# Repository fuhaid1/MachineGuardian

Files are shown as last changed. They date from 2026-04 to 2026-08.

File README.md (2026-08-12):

# Machine Guardian

> Non-intrusive machine access control and energy monitoring for workshops and labs.
> Built entirely on an ESP32 — no cloud required.

System Overview

## What it does

Machine Guardian clamps onto the power line of any machine and watches for current draw. Employees authenticate with an NFC card before starting the machine. If the machine is started without a valid card, the system triggers an alarm, flashes the red LED, sounds the buzzer, and sends a Telegram alert — all without cutting power or touching the machine's wiring.

A built-in web dashboard (served directly from the ESP32) shows live current draw, session history, employee usage, and unauthorized access events. All data can be downloaded as a multi-sheet Excel file.

---

## Feature overview

| Feature | Detail |
|---|---|
| **Non-intrusive sensing** | SCT-013 current clamp — no wiring modifications |
| **NFC authentication** | PN532 module, MIFARE ISO14443A cards/fobs |
| **Ambient cancellation** | Subtracts room noise baseline so low-power machines are detectable |
| **Live web dashboard** | Served from ESP32 PROGMEM, no SD card or external server |
| **Real-time chart** | Current draw chart updates every 2 seconds with ambient/threshold lines |
| **Demo data** | Chart pre-fills with 3 days of historical demo data on first boot |
| **Employee management** | Add/remove/deactivate employees via the website, stored in NVS flash |
| **Unauthorized tracking** | Tracks runtime and power usage of unauth machine starts separately |
| **Telegram alerts** | HTTPS POST directly from ESP32 on unauthorized access |
| **Excel export** | Download full dataset (power log, runtime, operator summary, event log) |
| **Persistent config** | Ambient baseline, threshold, and employees survive reboots via NVS |
| **Threshold control** | Set detection threshold from the Settings page, no reflashing needed |

---

## Hardware required

| Component | Notes |
|---|---|
| ESP32 DevKit (38-pin) | Any ESP32 with ADC on pin 34 |
| SCT-013 current clamp (100A/50mA) | Bare CT output — **not** the -030 voltage variant |
| PN532 NFC/RFID module V3 | Set DIP switches to I2C mode: 1=ON, 2=OFF |
| SSD1306 OLED 0.91" I2C | Address 0x3C |
| Red, Green, Yellow LEDs | 5mm, any colour |
| Active buzzer | 3.3V compatible |
| Resistors | 3× 220Ω (LEDs), 2× 10kΩ (bias divider), 1× 33Ω 1% metal film (burden) |
| Capacitors *(optional)* | 10µF electrolytic (bias filter), 100nF ceramic × 3 (decoupling) — recommended for PCB builds |

**NFC cards/fobs:** any MIFARE Classic or MIFARE Ultralight card works. The system reads the UID only.

---

## Wiring

### Pin assignments

| Signal | ESP32 Pin |
|---|---|
| SCT-013 ADC input | 34 |
| I2C SDA (PN532 + OLED) | 21 |
| I2C SCL (PN532 + OLED) | 22 |
| Green LED | 18 |
| Red LED | 19 |
| Yellow LED | 5 |
| Buzzer | 23 |

### SCT-013 bias and burden circuit

The SCT-013 100A/50mA is a bare current-transformer (CT) that outputs current proportional to the line current. It needs two external circuits:

**Burden resistor** — converts CT current output to a voltage the ADC can read.
- Solder a **33Ω 1% metal film** resistor directly across OUT+ and OUT-.
- At 100A primary, the CT outputs 50mA × 33Ω = **1.65V peak** — within the 3.3V ADC range.

**Bias voltage divider** — shifts the AC signal up so it stays positive (ADC only reads 0–3.3V).
- 3.3V → 10kΩ → **node** → 10kΩ → GND
- Connect the **node** to OUT+ and to ESP32 pin 34.
- Add a **10µF** capacitor between the node and GND to stabilise the DC midpoint.

```
3.3V ─── 10kΩ ─── NODE ─── 10kΩ ─── GND
                    │  │
                   34  33Ω (burden across CT terminals)
                        │
                       GND
```

### PN532 I2C mode

Set the two DIP switches on the PN532 module: **switch 1 = ON, switch 2 = OFF**.  
The module shares the I2C bus with the OLED (SDA → pin 21, SCL → pin 22).

### LED wiring

Each LED: `ESP32 pin → 220Ω resistor → LED anode → LED cathode → GND`

### Buzzer

Active buzzer: `+` to pin 23, `–` to GND. If your buzzer draws more than 40mA, add an NPN transistor driver (2N2222): base via 1kΩ from pin 23, collector to buzzer+/3.3V, emitter to GND.

---

## PCB soldering guide

When soldering the final board, the layout choices below eliminate the PN532 interference that plagues breadboard builds.

### Component placement zones

```
┌─────────────────────────────────────────────────┐
│  [CT Circuit]          │          [OLED]        │
│  Top-left corner       │       Top-right        │
│  Burden + bias divider │                        │
│  ADC trace ≤3cm        │                        │
│                        │                        │
│         [ESP32 — centre of board]               │
│                                                 │
│  [LEDs + Buzzer]       │       [PN532]          │
│  Bottom-left           │   Bottom-right corner  │
│                        │   As far from CT as    │
│                        │   possible             │
└─────────────────────────────────────────────────┘
```

### Critical rules

1. **Ground plane** — pour copper fill on the bottom layer. Connect every GND pad to the plane via vias. This single change eliminates the majority of ADC noise.

2. **Star ground** — all GND traces meet at one point (the ESP32 GND pin), not daisy-chained.

3. **Decoupling capacitors** *(optional but recommended)* — place within 2mm of each VCC pin if you have them:
   - PN532: 100nF ceramic + 10µF electrolytic
   - OLED: 100nF ceramic
   - ESP32 3.3V pin: 100nF ceramic
   
   The firmware's `Wire.end()` trick handles most interference without caps. They improve ADC stability on a soldered PCB but are not required for the system to work.

4. **I2C pull-ups** — 4.7kΩ from SDA to 3.3V, 4.7kΩ from SCL to 3.3V. Check if your PN532 module already has them before adding more.

5. **ADC trace isolation** — route the ADC trace (node → pin 34) away from I2C traces. If they must cross, do so at 90°.

6. **CT cable** — twisted pair, ≤15cm. If using shielded cable, connect the shield to GND at the PCB end only (not both ends — that creates a ground loop).

---

## Software setup

### Prerequisites

- [PlatformIO](https://platformio.org/) (VS Code extension or CLI)
- ESP32 Arduino core (installed automatically by PlatformIO)

### Installation

```bash
git clone https://github.com/YOUR_USERNAME/machine-guardian.git
cd machine-guardian
```

Open `src/main.cpp` and fill in your credentials (the only lines you need to edit):

```cpp
// Wi-Fi
const char* WIFI_SSID     = "YOUR_WIFI_SSID";
const char* WIFI_PASSWORD = "YOUR_WIFI_PASSWORD";

// Telegram — leave both blank ("") to disable alerts
const char* TELEGRAM_TOKEN   = "";   // from @BotFather
const char* TELEGRAM_CHAT_ID = "";   // your personal or group chat ID
```

Then flash:

```bash
pio run --target upload
pio device monitor   # watch boot log and see your device's IP
```

---

## Telegram bot setup

1. Open Telegram and message **@BotFather** → `/newbot` → follow prompts → copy the **token**.
2. Send any message to your new bot (this starts the chat).
3. Open this URL in a browser (replace `<TOKEN>` with yours):
   ```
   https://api.telegram.org/bot<TOKEN>/getUpdates
   ```
4. Find `"chat":{"id": 123456789}` in the response — that number is your **chat ID**.
5. Paste both values into `main.cpp` and reflash.

All Telegram calls run entirely on the ESP32 over HTTPS. No external server or intermediary is needed.

---

## First-time calibration

After flashing and connecting to WiFi, open the dashboard at `http://<ESP32-IP>` in any browser. The IP is printed in the serial monitor at boot and shown on the OLED.

### 1. Capture ambient baseline (required)

The current clamp picks up ~4A of room noise from nearby mains wiring. The ambient capture removes this.

1. Make sure the machine you are monitoring is **completely off**.
2. Go to **Settings → Ambient Calibration → Capture Ambient**.
3. Wait ~3 seconds. The device takes 30 samples, averages them, adds a 10% safety margin, and saves the result to flash.

You only need to redo this if you move the device to a different location.

### 2. Set detection threshold (optional)

The default threshold is **1.0A net** (above ambient). This works for most machines.

- Go to **Settings → Detection Threshold**.
- If you get false triggers (machine detected when off), increase the threshold.
- If your machine isn't being detected, decrease it.
- Changes are saved to flash immediately.

### 3. Add employees

1. Have each employee scan their card on the NFC reader.
2. The UID appears in the Event Log as `Unknown card: XXXXXXXX`.
3. Go to **Employees → Add New Employee**, click "Use this UID", enter their name, click "Add & Save".

Employee records are stored in NVS flash and survive all reboots and firmware updates.

---

## Web dashboard

Open `http://<ESP32-IP>` from any device on the same WiFi network.

### Dashboard page

| Element | Description |
|---|---|
| Machine banner | Current state: Idle / Authenticated / Running / Unauthorized |
| Live current gauge | Raw amps with visual markers for ambient level and detection threshold |
| Net current | Raw minus ambient — what the detection logic uses |
| Power chart | Current draw over time with dashed lines for ambient and threshold. Demo data fills the past 3 days; real data appears at a "▶ NOW" divider |
| Runtime chart | Authorised (green) vs unauthorised (red) machine time per day |
| Usage pie | Per-employee runtime breakdown (real data only) |
| Event log | Every state change, NFC scan, and alert with timestamps |

### Employees page

- View all registered employees and their total runtime.
- Unauthorised usage appears as a red row at the bottom.
- Add new employees from UID scans or manual entry.
- Deactivate employees (blocks their card without deleting the record).

### Settings page

- **Detection threshold** — change without reflashing.
- **Ambient calibration** — recapture the noise baseline.
- **Download Excel** — exports Power Log, Runtime by Day, Operator Summary, and Event Log as a `.xlsx` file. Demo data is excluded from all sheets.
- **Device info** — live ADC readings for debugging.

---

## System behaviour

### State machine

```
         ┌──────────────────────────────────────────────────┐
         │                                                  │
    ┌────▼────┐   Valid NFC scan   ┌───────────────┐        │
    │  IDLE   ├───────────────────►│ AUTHENTICATED │        │
    │ Red LED │                    │  Yellow LED   │        │
    └────┬────┘                    └──────┬────────┘        │
         │                               │                  │
         │ Machine ON                    │ Machine ON       │
         │ (no auth)                     │ (within 30s)     │
         │                               │                  │
    ┌────▼──────────┐            ┌───────▼────────┐         │
    │ UNAUTHORIZED  │            │    RUNNING     │         │
    │ Red flash     │            │   Green LED    ├─────────┘
    │ Buzzer alarm  │            │ Tracks runtime │ Machine OFF
    │ Telegram alert│            └────────────────┘
    └───────────────┘
         │ (auto-returns to IDLE after alarm)
```

- **Auth timeout:** if a valid card is scanned but the machine is not started within 30 seconds, the system returns to IDLE.
- **Unauthorized tracking:** the duration between an unauthorized start and the machine turning off is logged under `UNAUTHORIZED` in the runtime charts.
- **Unknown card:** scanning an unregistered card logs a warning and shows the UID on the OLED and in the Event Log, but does not trigger the alarm.

### Current measurement

The firmware pauses the I2C bus while taking ADC samples (`Wire.end()` / `Wire.begin()`). This eliminates the PN532's switching noise from coupling into the ADC — reducing the ambient from ~4–8A down to ~0.7A on a breadboard. On a properly decoupled PCB this step is harmless and can be left in.

Measurement formula:
```
rmsVolts = sqrt(mean(samples²)) × (3.3V / 4095)
rawAmps  = (rmsVolts / BURDEN_OHM) × TURNS_RATIO
netAmps  = max(rawAmps − gAmbientAmps, 0)
filtered = 0.15 × netAmps + 0.85 × filtered   ← exponential moving average
```

---

## API reference

The ESP32 exposes a simple REST API used by the dashboard. All endpoints return JSON.

| Method | Endpoint | Description |
|---|---|---|
| GET | `/` | Dashboard HTML |
| GET | `/api/status` | Live sensor state, amps, employee, session runtime |
| GET | `/api/power` | Power log (last 24h, 5s interval, machine-on sessions only) |
| GET | `/api/runtime` | Runtime entries by date and employee |
| GET | `/api/notifications` | Event log (last 50 events) |
| GET | `/api/set_ambient` | Capture and save ambient baseline |
| GET | `/api/employees` | Employee list (name + active status, **no UIDs**) |
| POST | `/api/employees/add` | `{"name":"...","uid":"..."}` |
| POST | `/api/employees/remove` | `{"index": N}` |
| POST | `/api/employees/toggle` | `{"index": N}` — activate/deactivate |
| POST | `/api/employees/clear` | Delete all employees |
| POST | `/api/set_threshold` | `{"threshold": 1.5}` — net amps |

---

## NVS storage layout

Employee records and calibration values are stored in the `guardian` NVS namespace.

| Key | Type | Value |
|---|---|---|
| `emp_count` | int | Number of registered employees |
| `emp_uid_N` | string | Card UID for employee N |
| `emp_name_N` | string | Name for employee N |
| `emp_act_N` | uint8 | 1 = active, 0 = deactivated |
| `ambient` | float | Ambient baseline in amps |
| `threshold` | float | Detection threshold in net amps |

NVS survives normal firmware flashes. To fully reset, use `pio run -t erase` (erases the entire flash including NVS).

---

## Troubleshooting

### Ambient reads 4–8A with machine off

The PN532 is coupling noise into the ADC via shared power rails. The firmware already calls `Wire.end()` before sampling to mitigate this. If it persists:
- Verify I2C and ADC traces don't run parallel on the PCB.
- Add 100nF + 10µF decoupling caps to the PN532 VCC pin.
- Recapture ambient from the Settings page after the PCB is soldered.

### ESP32 resets when scanning unknown NFC card

Fixed in the current firmware. The crash was a `LoadProhibited` fault from `uidLen = 0` being passed to the UID string builder. The fix guards `uidLen` before any byte access.

### Machine not detected / threshold too high

1. Go to **Settings → Ambient Calibration** and recapture with the machine off.
2. Go to **Settings → Detection Threshold** and lower it. A monitor typically draws 1.5–3A net above ambient.

### OLED not found

Verify the I2C address. Most SSD1306 0.91" modules are `0x3C`. Change `OLED_ADDR` in the firmware if yours is `0x3D`.

### PN532 not found at boot

Verify DIP switch position: switch 1 = ON (towards the dot), switch 2 = OFF. I2C mode is the only one supported by this firmware.

### WiFi not connecting

The firmware tries for 15 seconds then boots in offline mode. The dashboard is still served; only Telegram alerts and NTP time sync require WiFi.

---

## Configuration reference

All tuneable constants are near the top of `src/main.cpp`:

```cpp
// Sensor — match to your specific CT model
const float BURDEN_OHM  = 33.0f;    // burden resistor value in ohms
const float TURNS_RATIO = 2000.0f;  // CT primary/secondary ratio (100A / 0.05A)

// EMA filter — higher alpha = faster response but more noise
const float LP_ALPHA = 0.15f;

// Auth timeout — seconds before authenticated state reverts to idle
const unsigned long AUTH_TIMEOUT_MS = 30000;

// Power log interval — how often to store a sample during a running session
const unsigned long POWER_SAMPLE_INTERVAL = 5000;  // ms

// OLED I2C address — 0x3C on most modules, 0x3D on some
#define OLED_ADDR 0x3C

// Timezone offset for NTP — 3*3600 = UTC+3 (Saudi Arabia)
configTime(3 * 3600, 0, "pool.ntp.org");
```

Threshold and ambient are runtime-configurable from the Settings page and do not require reflashing.

---

## Project structure

```
machine-guardian/
├── src/
│   └── main.cpp          # Full firmware — ESP32 C++ with embedded HTML dashboard
├── docs/
│   ├── wiring.md         # Detailed wiring tables and PCB layout notes
│   └── api.md            # Full API documentation with example responses
├── hardware/
│   └── bom.md            # Bill of materials with part numbers
├── platformio.ini         # PlatformIO build config and library dependencies
├── .gitignore
├── LICENSE
└── README.md
```

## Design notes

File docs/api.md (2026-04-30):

# API Reference

The ESP32 serves a REST API on port 80. All responses are JSON unless noted.

## GET /api/status

Live system state. Called every 2 seconds by the dashboard.

**Response:**
```json
{
  "state": 0,
  "machine_on": false,
  "employee": "",
  "raw_amps": 4.218,
  "ambient_amps": 4.102,
  "net_amps": 0.000,
  "midpoint": 1834.6,
  "threshold": 1.0,
  "session_runtime_sec": 0
}
```

| Field | Type | Description |
|---|---|---|
| `state` | int | 0=idle, 1=authenticated, 2=running, 3=unauthorized |
| `machine_on` | bool | Whether net amps ≥ threshold |
| `employee` | string | Name of authenticated employee, or "" |
| `raw_amps` | float | RMS amps before ambient subtraction |
| `ambient_amps` | float | Saved ambient baseline |
| `net_amps` | float | EMA-filtered net amps (raw − ambient) |
| `midpoint` | float | Current ADC DC midpoint (debug) |
| `threshold` | float | Current detection threshold |
| `session_runtime_sec` | int | Seconds current session has been running |

---

## GET /api/power

Power log for the current 24h window. Only samples captured during active (authorised) sessions are stored.

**Response:**
```json
[
  { "ts": 1748600000, "amps": 3.82, "watts": 840.0 },
  { "ts": 1748600005, "amps": 3.91, "watts": 860.2 }
]
```

Maximum 288 entries (circular buffer). Sampled every 5 seconds during running state.

---

## GET /api/runtime

Session runtime log grouped by date and employee.

**Response:**
```json
[
  { "date": "2025-05-28", "employee": "Ahmed Al-Rashid", "seconds": 14400, "unauthorized": false },
  { "date": "2025-05-28", "employee": "UNAUTHORIZED",    "seconds": 1200,  "unauthorized": true  }
]
```

Up to 100 entries. Combined per employee per day (multiple sessions on the same day are summed).

---

## GET /api/notifications

Event log. Most recent 50 events.

**Response:**
```json
[
  { "timestamp": 1748600100, "message": "Ahmed Al-Rashid authenticated", "type": "info" },
  { "timestamp": 1748600400, "message": "Unauthorized machine start detected!", "type": "alarm" }
]
```

| `type` | Meaning |
|---|---|
| `info` | Normal events (login, machine start/stop) |
| `warn` | Non-critical alerts (unknown card, auth timeout) |
| `alarm` | Unauthorized machine start |

---

## GET /api/employees

Returns employee list. UIDs are intentionally excluded from this response.

**Response:**
```json
[
  { "name": "Ahmed Al-Rashid", "active": true },
  { "name": "Sara Mohammed",   "active": false }
]
```

---

## POST /api/employees/add

Add a new employee and persist to NVS.

**Body:**
```json
{ "name": "Khalid Hassan", "uid": "A1B2C3D4" }
```

**Response:** `{"ok":true}` or HTTP 400/507 on error.

UID must be uppercase hex string (no spaces, no dashes). Maximum 20 employees.

---

## POST /api/employees/remove

Remove employee at index N (0-based, from `/api/employees` order).

**Body:**
```json
{ "index": 2 }
```

**Response:** `{"ok":true}`

This permanently deletes the employee from NVS.

---

## POST /api/employees/toggle

Toggle active/inactive state for employee at index N.

**Body:**
```json
{ "index": 0 }
```

**Response:** `{"ok":true}`

Deactivated employees' cards are rejected at the reader but their records are kept.

---

## POST /api/employees/clear

Delete all employees from NVS. Cannot be undone.

**Body:** (empty)

**Response:** `{"ok":true}`

---

## GET /api/set_ambient

Captures a new ambient baseline. Takes ~3 seconds.

**Important:** call this only with the monitored machine completely off.

**Response:**
```json
{
  "raw_avg": 3.729,
  "ambient_amps": 4.102,
  "threshold": 1.0
}
```

| Field | Description |
|---|---|
| `raw_avg` | Average of 30 raw RMS samples |
| `ambient_amps` | Saved value (raw_avg × 1.1 — includes 10% safety margin) |
| `threshold` | Current detection threshold (unchanged) |

---

## POST /api/set_threshold

Update the detection threshold. Persisted to NVS.

**Body:**
```json
{ "threshold": 1.5 }
```

Valid range: 0.1 – 50.0 amps.

**Response:** `{"ok":true}` or HTTP 400 if out of range.

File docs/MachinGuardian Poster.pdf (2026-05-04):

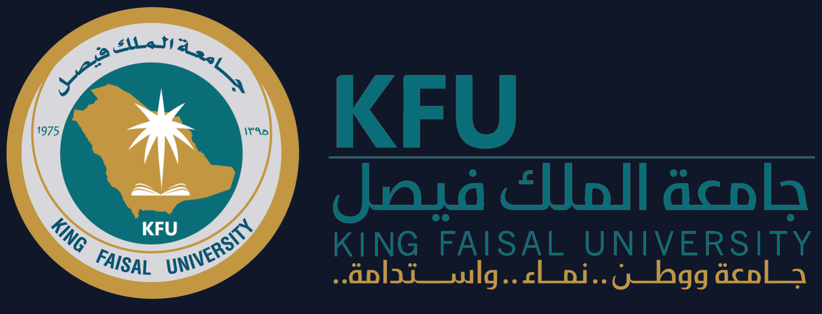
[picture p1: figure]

Fehaid Ali Alshishaee · 222403548 Hassan Ibrahim Rawagah · 222416197 Ali Abdullah Albaik · 223036886
Ali Jawad Al-Mutawah · 222424050 Supervisor: Dr. Rama Sami

# Machine Guardian

# A B S T R A C T

Machine Guardian is an integrated IoT security system that restricts industrial equipment access to NFCauthenticated personnel while monitoring real-time energy consumption. The ESP32 microcontroller implements an event-driven state machine, a "Silencing Protocol" for EMI-free ADC sampling, and ambient-baseline cancellation for accurate net current measurement. Data is visualised on a locally-hosted web dashboard with live charts, Excel export, and automated Telegram alerts — requiring no cloud infrastructure.

N O N - I N T R U S I V E I N D U S T R I A L A C C E S S C O N T R O L & E N E R G Y M O N I T O R I N G · E S P 3 2 I O T S Y S T E M

## N O N- INTRUSIVE SENSIN G

The SCT-013 current clamp attaches directly to the machine's power cable — no wiring modifications, no downtime. The CT outputs 50 mA at 100 A primary, converted by a 33 Ω burden resistor to a voltage readable by the ESP32 ADC

## NF C A C C ESS C O NTR O L

The PN532 module reads MIFARE ISO14443A cards. UIDs are validated against an employee table stored in the ESP32's NonVolatile Storage (NVS), persisting through power cycles. Employees can be added, removed, or deactivated live from the web dashboard.

IDLE Scan card
AUTH 30 s window
RUNNING Current detected

K I N G F A I S A L U N I V E R S I T Y · C C S I T · E M B E D D E D S Y S T E M S

T E A M M E M B E R S

## LIVE WEB DASHB O ARD

Served directly from ESP32 PROGMEM — no SD card, no external server. The Chart.js
dashboard shows live current draw with ambient and threshold reference lines, runtime by day, operator usage pie chart, and a full event log with timestamps.

## AMBIENT C AN C ELLATI O N

Room wiring induces 4–8 A of apparent current even with no machine running. The system captures a 30-sample baseline with the machine off, adds a 10% safety margin, and subtracts it from every reading — reducing the effective noise floor to <0.3 A net.

## TELE G RAM ALERTS

On unauthorized access, the ESP32 sends an HTTPS POST directly to api.telegram.org using WiFiClientSecure — no intermediary server required. The supervisor receives an instant alert with timestamp and location. All compute stays on-device.

## O FFLINE EX C EL EXP O RT

SheetJS builds a multi-sheet .xlsx file entirely in the browser — Power Log, Runtime by Day, Operator Summary, and Event Log. Demo data is excluded from all sheets. The file contains only real machine sessions with timestamps and net amperage

Sheet 1 · Power Log (raw + net A, W)
Sheet 2 · Runtime by Day
Sheet 3 · Operator Summary Sheet 4 · Event Log

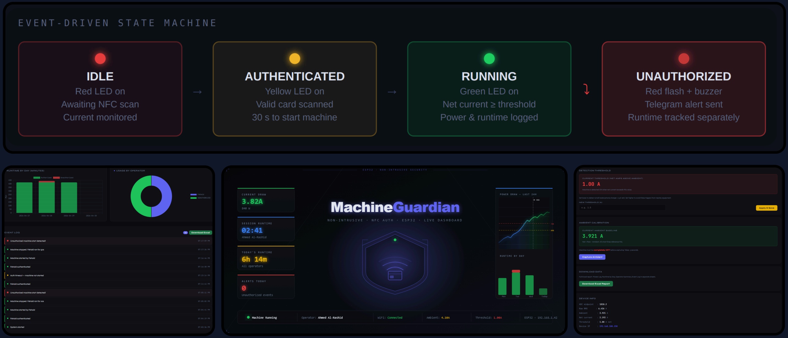
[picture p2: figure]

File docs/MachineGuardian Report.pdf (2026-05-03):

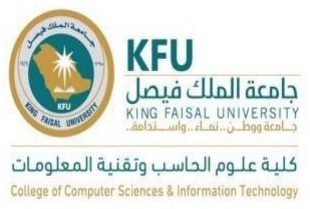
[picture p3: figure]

King Faisal University

College of Computer Sciences and Information Technology

Embedded systems

Project title:

## Machine Guardian

Members:

Fehaid Ali Alshishaee – 222403548

Hassan Ibrahim Rawagah – 222416197

Ali Abdullah Albaik – 223036886

Ali Jawad Al-Mutawah - 222424050

## Dr: Rama Sami

## Abstract

This report details the development of "Machine Guardian," an integrated IoT system designed to enhance industrial safety, access control, and energy management. Utilizing the ESP32 microcontroller as a central logic unit, the system combines Near Field Communication (NFC) for identity verification with non-invasive current sensing (SCT-013) to monitor heavy machinery. The architecture ensures that equipment operation is restricted to authorized personnel while providing real- time data on power consumption and operational efficiency. Key features include a locally-hosted web dashboard for data visualization, automated Telegram alerts for unauthorized usage, and an event-driven state machine to ensure deterministic behavior. Experimental results demonstrate the effectiveness of the "Silencing Protocol" in reducing electromagnetic interference during analog sampling and the reliability of True RMS calculations for accurate power logging.

## Introduction

The Machine Guardian is an integrated IoT solution designed for industrial equipment monitoring, access control, and energy management. Utilizing the ESP32 microcontroller, the system serves as a "smart gatekeeper" for heavy machinery. By combining NFC (Near Field Communication) for identity verification and non-invasive Current Sensing (SCT-013), the system ensures that only authorized personnel can operate equipment while providing real-time data on power consumption and operational efficiency.
The system is further enhanced by a locally-hosted web dashboard and automated Telegram alerts, providing supervisors with immediate visibility into unauthorized usage or equipment status.

## Problem Statement

Heavy machinery in industrial settings is often prone to unauthorized operation, which poses significant safety risks and leads to unmonitored energy expenditure. Traditional monitoring methods frequently suffer from: (1) Lack of Access Control, making it difficult to ensure only certified personnel operate specific machines; (2) Inaccurate Sensing due to ambient noise and electromagnetic interference (EMI); and (3) Delayed Notifications in the event of unauthorized use.

## System Architecture

The firmware acts as the central logic unit for a multi-modular hardware stack. Its primary components include:
Access Control: A PN532 NFC module validates user credentials against a local database stored in the ESP32’s Non-Volatile Storage (NVS). Sensing & Math: The SCT-013 sensor captures AC current through a burden resistor. The software performs a true RMS (Root Mean Square) calculation to determine actual amperage.
User Interface: A 0.91" SSD1306 OLED displays status, while a buzzer and a three-stage LED system (Red/Yellow/Green) provide visual and audible feedback.
Connectivity: The device operates as a web server, hosting a sophisticated JavaScript-based dashboard for data visualization and employee management. It also functions as a Telegram client for remote notifications.

## Hardware Design

The hardware selection focuses on non-invasive installation and low-latency processing. Key components include the ESP32 for dual-core processing, the SCT-013 current sensor for non-contact detection, and a feedback system comprising a 0.91" SSD1306 OLED and a 3-stage LED (Red/Yellow/Green) to indicate machine states.

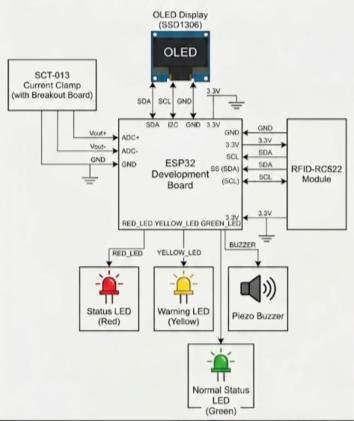
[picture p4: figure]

## Software Design

The firmware utilizes an Event-Driven State Machine to maintain high reliability. The logic transitions through states: IDLE, AUTHENTICATED, RUNNING, and UNAUTHORIZED based on NFC verification and current thresholds.
A. Step-by-Step Algorithm
1. Initialize I2C, SPI, and Wi-Fi; load employee records.
2. Wait for NFC scan while monitoring baseline current.
3. Validate UID against local NVS database.
4. Open a 30-second window for machine start if authorized.
5. Halt I2C bus (Silencing Protocol) and take 2000 samples.
6. Calculate True RMS current.
7. Trigger alarm and Telegram alert if current > 1.0A without auth.
B. Flowchart Description
The system flow initiates at the NFC scan. A decision branch validates the user; success triggers the operational window. Concurrently, the current sensing loop monitors for draw. If draw exceeds the threshold without a valid session, the UNAUTHORIZED state is entered, triggering the alarm system.

## Use case Diagram:

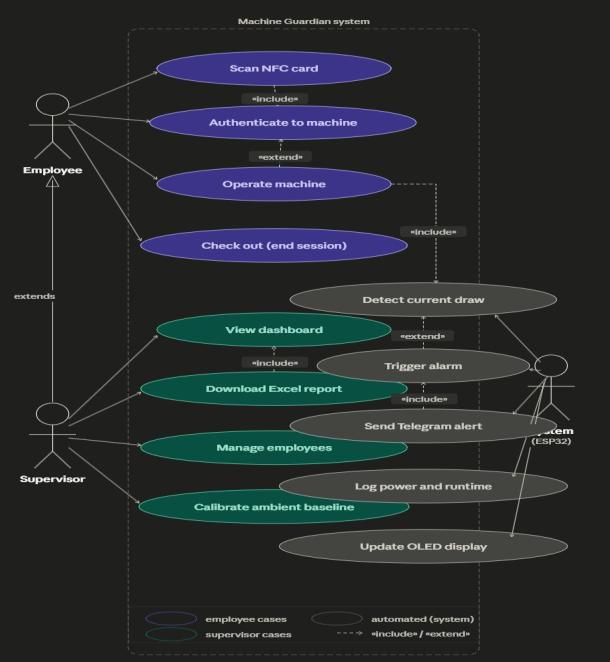
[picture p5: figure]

## Class Diagram:

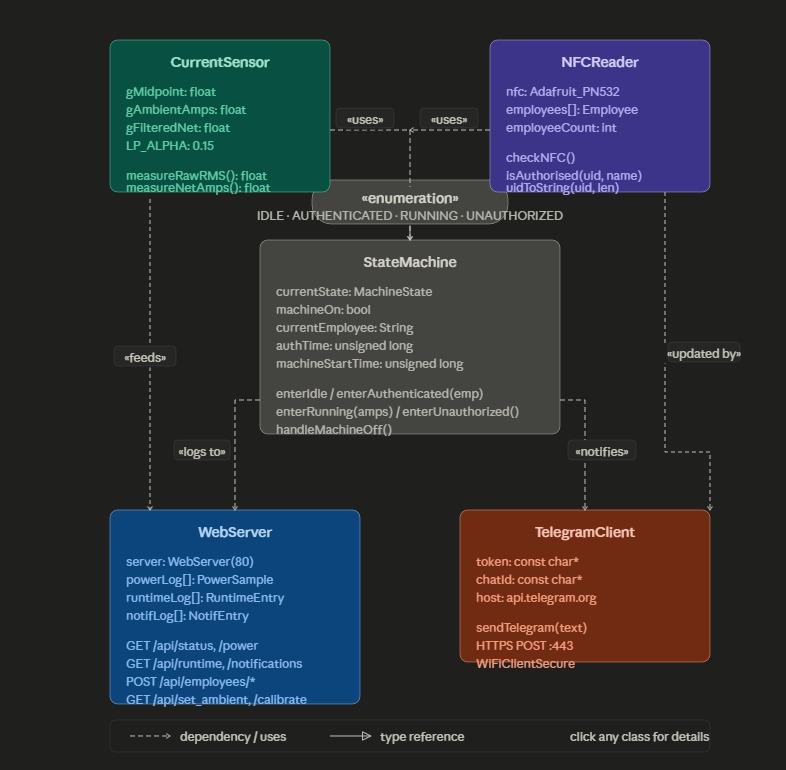
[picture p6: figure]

## Methodology

The firmware is structured using an Event-Driven State Machine architecture to ensure high reliability and low-latency response times.
A. Signal Processing & Interference Mitigation Because the ESP32’s Analog-to-Digital Converter (ADC) is sensitive to high-frequency noise, the methodology includes a "Silencing Protocol." During current sampling, the firmware temporarily halts the I2C bus (Wire.end()) to prevent the OLED and NFC modules from injecting electromagnetic interference into the analog readings.
The current is calculated using the following logical flow:
Sampling: 2000 samples are taken over a specific window.
Offset Correction: A dynamic midpoint (bias) is tracked using an Exponential Moving Average (EMA) to account for thermal drift in the DC bias circuit.
RMS Conversion: The raw samples are squared, averaged, and then the square root is taken to obtain the effective current.
B. State Management
The system transitions through four primary states:
IDLE: Machine is off; waiting for a valid NFC tag.
AUTHENTICATED: A valid tag is scanned; a 30-second window is granted to start the machine.
RUNNING: The sensor detects current above the threshold (1.0A); runtime and power logs are updated.
UNAUTHORIZED: Current is detected without a prior NFC scan; the system triggers an alarm and sends a high-priority Telegram alert.
C. Data Persistence & Analytics
Employee records and calibration data are saved using the Preferences library, ensuring the device remains functional after a power cycle without needing an external database. The web dashboard uses Chart.js for client-side rendering of power logs and SheetJS to allow users to export the RuntimeEntry logs into Excel format.

## Results and Discussion

The "Silencing Protocol" proved critical, as I2C bus activity previously injected noise into analog readings. By pausing the bus during sampling, a stable current baseline was achieved.

## Testing

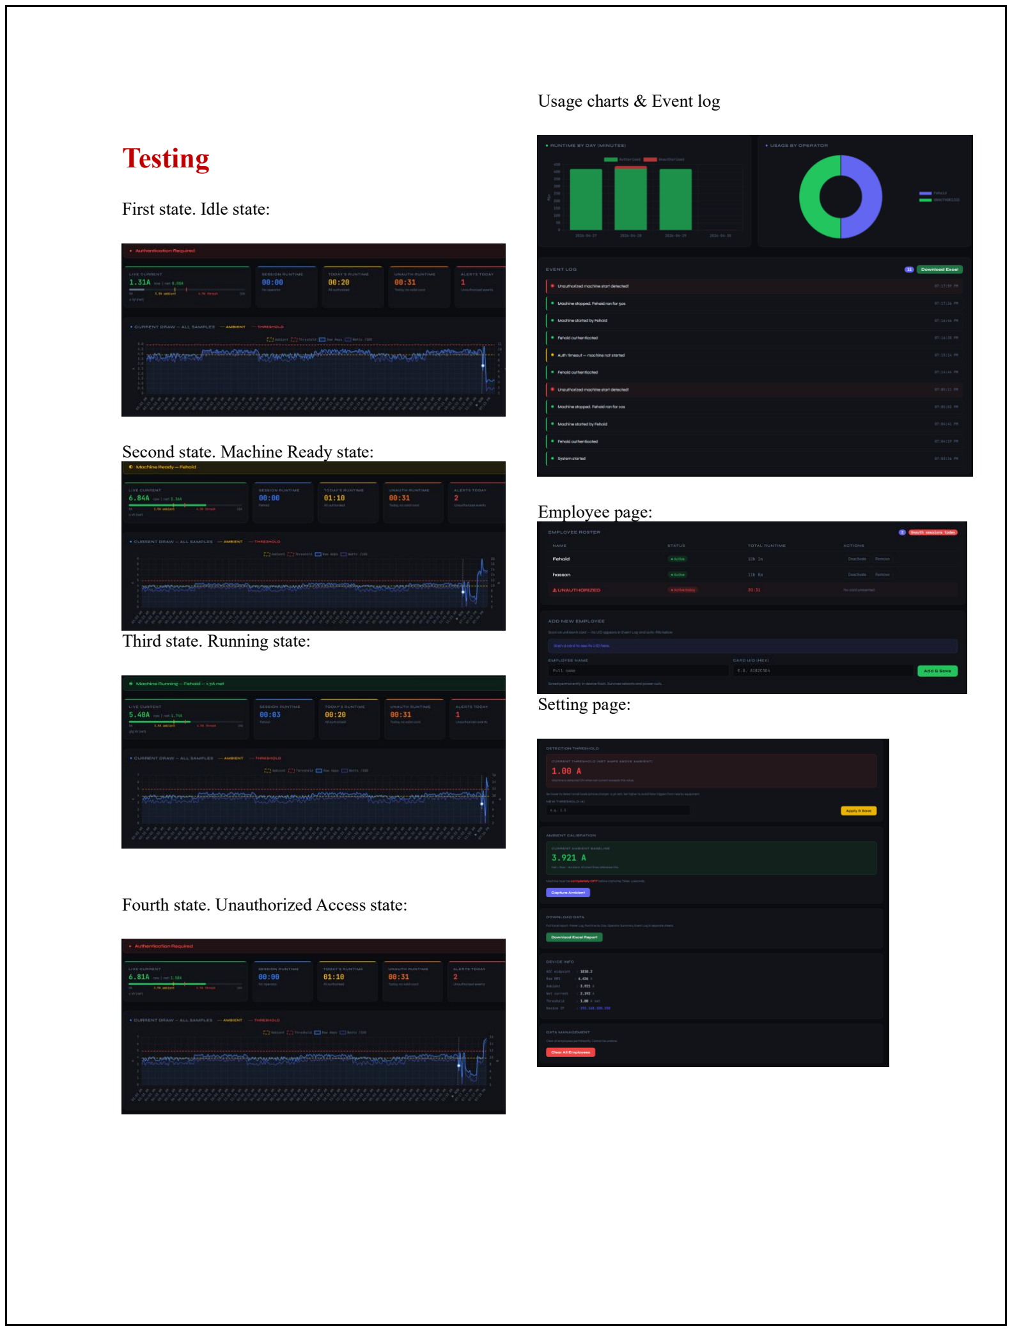
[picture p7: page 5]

First state. Idle state:

Second state. Machine Ready state:

Third state. Running state:

Fourth state. Unauthorized Access state:

Usage charts & Event log

Employee page:

Setting page:

Offline downloaded Excel sheet:

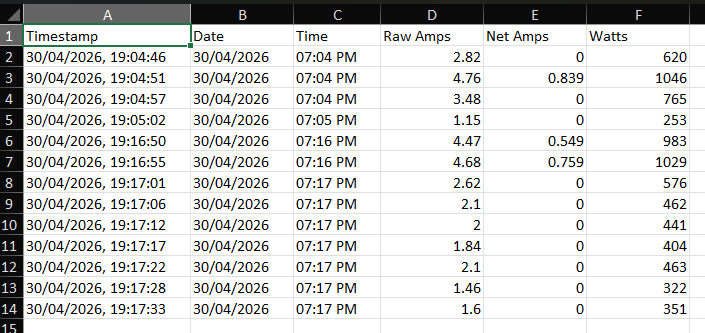
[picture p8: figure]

Telegram bot warning:

## Challenges and Solutions

1-Accurate AC Measurement: Standard analog samples don't reflect true power
consumption.
Solution: True RMS calculation (Squaring, Averaging, and Square Rooting)
across 2000 samples
2-Current Clamp Inaccuracy (Ambient Noise): External magnetic fields and environmental factors often caused the SCT-013 sensor to report non-zero readings even when the machine was off.
Solution: We implemented an ambient calibration function that baselines the sensor in its environment before operation, ensuring that only actual machine current is measured
3- Unauthorized Operation: Heavy machinery could be used without oversight or digital logging.
Solution: Developed an Event-Driven State Machine that triggers an alarm and a Telegram alert if current exceeds 1.0A without a successful NFC authentication

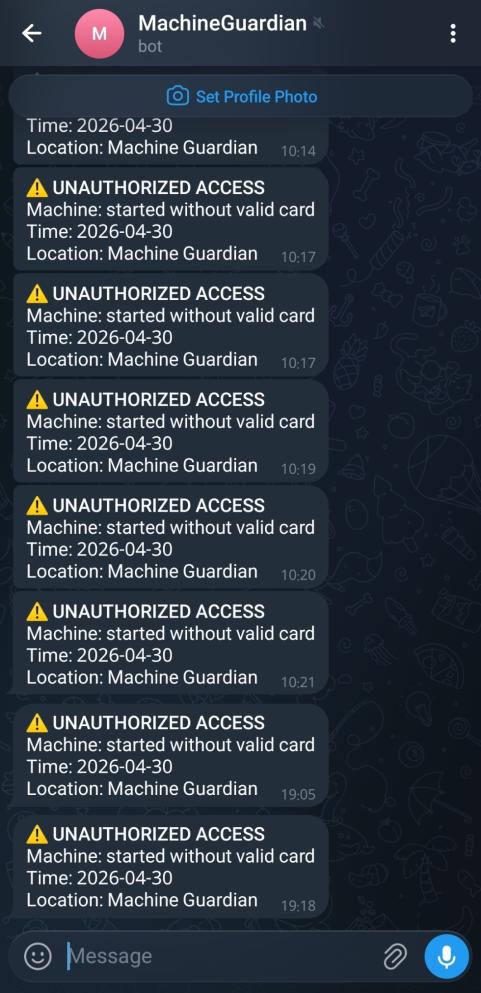
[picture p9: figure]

## Conclusion

The Machine Guardian firmware provides a robust framework for enhancing industrial safety and accountability. By integrating physical security (NFC) with electrical monitoring (CT Sensors), it bridges the gap between manual operation and digital oversight.
The inclusion of an "Unauthorized" state and automated reporting features significantly reduces the risk of equipment misuse and helps management track precise energy costs per operator. Future iterations could expand on this by implementing MQTT for enterprise-level cloud integration or adding vibration sensors for predictive maintenance.

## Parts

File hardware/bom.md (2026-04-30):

# Bill of Materials

| # | Component | Specification | Qty | Notes |
|---|---|---|---|---|
| 1 | ESP32 DevKit | 38-pin, 4MB flash | 1 | Any standard ESP32 DevKit works |
| 2 | SCT-013 current clamp | 100A / 50mA, bare CT output | 1 | Do **not** use the -030 (voltage output) variant |
| 3 | PN532 NFC/RFID module | V3, I2C/SPI/UART | 1 | Set DIP to I2C mode before soldering |
| 4 | SSD1306 OLED display | 0.91 inch, I2C, 128×32 | 1 | Address 0x3C (most common) |
| 5 | Active buzzer | 3.3V or 5V (active = self-oscillating) | 1 | Not a passive piezo element |
| 6 | LED — red | 5mm, standard | 1 | Any red LED, ~2V Vf |
| 7 | LED — green | 5mm, standard | 1 | Any green LED, ~2.2V Vf |
| 8 | LED — yellow | 5mm, standard | 1 | Any yellow LED, ~2.1V Vf |
| 9 | Resistor 220Ω | 1/4W, ±5% | 3 | LED current limiting |
| 10 | Resistor 10kΩ | 1/4W, ±1% | 2 | Bias voltage divider. Use 1% for stable midpoint |
| 11 | Resistor 33Ω | 1/4W, ±1% **metal film** | 1 | Burden resistor — metal film is lower noise than carbon |
| 12 | Resistor 4.7kΩ | 1/4W, ±5% | 2 | I2C pull-ups (if not on PN532 module) |
| 13 | NFC card or fob | MIFARE Classic or Ultralight | ≥1 | Any 13.56MHz ISO14443A card |
| 14 | USB cable | Micro-USB or USB-C (match ESP32) | 1 | Power supply |
| 15 | USB power supply | 5V, ≥1A | 1 | Phone charger works fine |

### Optional — decoupling capacitors

Not required for basic operation. Recommended for soldered PCB builds to improve noise rejection and ADC stability. The firmware's `Wire.end()` trick handles interference without them on a breadboard.

| # | Component | Specification | Qty | Notes |
|---|---|---|---|---|
| C1 | Capacitor 10µF | Electrolytic, 10V+ | 1 | Bias midpoint filter — reduces ADC flicker |
| C2 | Capacitor 100nF | Ceramic, 0.1µF, 10V+ | 3 | Decoupling — one per module VCC pin (PN532, OLED, ESP32) |

## Optional — for PCB build

| # | Component | Specification | Qty | Notes |
|---|---|---|---|---|
| P1 | 2.54mm pin headers | Male/female, through-hole | assorted | For module sockets |
| P2 | 3.5mm screw terminal | 2-pin | 1 | For CT sensor connection |
| P3 | NPN transistor | 2N2222 or BC547 | 1 | Only needed if buzzer draws >40mA |
| P4 | Resistor 1kΩ | 1/4W | 1 | Transistor base resistor (if using transistor) |
| P5 | Shielded 2-wire cable | Twisted pair, microphone cable | ~15cm | For CT sensor connection to PCB |

## Sourcing notes

- **SCT-013 (100A/50mA):** Search for "SCT-013-000" (bare CT, no built-in burden). Available on AliExpress, Amazon. The "-030" suffix indicates a built-in burden and voltage output — this is a different product requiring different firmware constants.
- **PN532 V3 module:** The blue module with solder-bridge or DIP switch for interface selection. Ensure it has exposed SDA/SCL pads.
- **OLED 0.91" SSD1306:** I2C variant (4-pin: VCC, GND, SCL, SDA). Not the SPI variant.
- **Active buzzer:** Must be self-oscillating (active), not a passive piezo element. Active buzzers buzz when you connect 3.3V directly. Passive ones need a PWM signal.

## Total estimated cost

| Category | Approximate cost |
|---|---|
| ESP32 | $3–6 |
| SCT-013 clamp | $5–10 |
| PN532 module | $4–8 |
| OLED display | $2–4 |
| Passives + LEDs | $2–4 |
| Capacitors (optional) | $1–2 |
| NFC cards (5-pack) | $3–6 |
| **Total (without caps)** | **~$19–38 USD** |
| **Total (with caps)** | **~$20–40 USD** |

Prices vary by source and shipping. Buying from AliExpress is significantly cheaper but has longer delivery times.

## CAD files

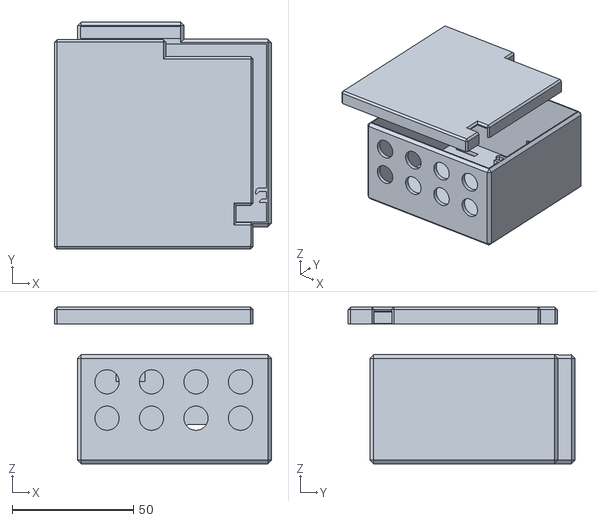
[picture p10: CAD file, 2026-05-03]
docs/MachineGuardian Case.stl
89.4 x 93.6 x 64.6

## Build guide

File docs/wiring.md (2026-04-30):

# Wiring Reference

## Pin assignments

| Signal | ESP32 Pin | Notes |
|---|---|---|
| SCT-013 ADC | 34 | Input-only ADC, no pull-up needed |
| I2C SDA | 21 | Shared: PN532 + OLED |
| I2C SCL | 22 | Shared: PN532 + OLED |
| Green LED | 18 | 220Ω to GND |
| Red LED | 19 | 220Ω to GND |
| Yellow LED | 5 | 220Ω to GND |
| Buzzer | 23 | Active buzzer, + to pin, – to GND |

## SCT-013 circuit (100A/50mA bare CT)

```
                    3.3V
                     │
                   10kΩ
                     │
CT OUT+ ────────── NODE ──── PIN 34
                     │
                 10µF (optional, to GND — stabilises midpoint)
                     │
CT OUT- ────────── GND
         │
        33Ω (burden, soldered across CT terminals)
```

Calculation:
- CT secondary: 50mA at 100A primary
- Burden voltage: 50mA × 33Ω = 1.65V peak (RMS ~1.17V)
- Fits 0–3.3V ADC range with room to spare

## PN532 NFC module

DIP switch configuration for I2C mode:
```
  DIP-1  DIP-2
  [ON ]  [OFF]
```

Connections:
```
PN532 SDA  →  ESP32 PIN 21
PN532 SCL  →  ESP32 PIN 22
PN532 VCC  →  3.3V
PN532 GND  →  GND
```

I2C pull-ups: 4.7kΩ from SDA to 3.3V and SCL to 3.3V.
Many PN532 V3 modules include these on-board — check with a multimeter before adding external ones.

## SSD1306 OLED (0.91")

```
OLED SDA  →  ESP32 PIN 21  (same I2C bus as PN532)
OLED SCL  →  ESP32 PIN 22
OLED VCC  →  3.3V
OLED GND  →  GND
```

Default I2C address: `0x3C`. If your module uses `0x3D`, change `OLED_ADDR` in the firmware.

## LEDs

```
ESP32 PIN  →  220Ω  →  LED anode  →  LED cathode  →  GND

PIN 18: Green
PIN 19: Red
PIN 5:  Yellow
```

## Buzzer

Active buzzer (the kind that beeps when you apply voltage directly):
```
+ lead  →  PIN 23
– lead  →  GND
```

If the buzzer draws more than 40mA, add an NPN transistor (2N2222):
```
PIN 23  →  1kΩ  →  Base
                   Collector  →  Buzzer+  →  3.3V
                   Emitter   →  GND
Buzzer– → GND
```

## PCB layout notes

### Why layout matters

On a breadboard, the PN532's 13.56MHz oscillator noise couples into the ADC through shared power rails and parallel wire runs. Proper PCB layout eliminates this without software workarounds.

### Placement zones

```
┌──────────────────────────────────────────────┐
│                                              │
│  CT CIRCUIT          │        OLED           │
│  (top-left)          │     (top-right)       │
│                      │                       │
│  ────────────────────┤                       │
│                      │                       │
│           ESP32 (centre)                     │
│                      │                       │
│  ────────────────────┤                       │
│                      │                       │
│  LEDs + BUZZER       │      PN532            │
│  (bottom-left)       │  (bottom-right)       │
│                      │                       │
└──────────────────────────────────────────────┘
```

CT circuit and PN532 in opposite corners = maximum separation between the noise source and the sensitive analog circuit.

### Ground plane

Pour a copper fill on the bottom layer. Connect every GND pad through a via to the ground plane. Use a single star-ground point at the ESP32 GND pin.

This alone removes most of the ADC noise.

### Decoupling capacitors (recommended, not required)

Place within 2mm of each module's VCC pin if available. The firmware's `Wire.end()` trick already handles most interference on a breadboard, but caps improve stability on a soldered PCB.

| Module | Caps |
|---|---|
| PN532 | 100nF ceramic + 10µF electrolytic |
| OLED | 100nF ceramic |
| ESP32 3.3V pin | 100nF ceramic |

If you don't have caps, the system will still work — ambient calibration will compensate for any remaining noise.

### CT cable

| Property | Recommendation |
|---|---|
| Length | ≤ 15cm. Never exceed 30cm. |
| Type | Twisted pair. Twist every ~2cm. |
| Shielding | Use shielded cable if available. Ground the shield at the **PCB end only** — grounding both ends creates a ground loop. |

Twisted pair reduces inducted EMF from nearby mains cables by ~10x compared to untwisted parallel wires.

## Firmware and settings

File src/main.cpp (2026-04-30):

/*
 * Machine Guardian — ESP32 Security System Firmware
 * SCT-013 100A/50mA + PN532 NFC + SSD1306 OLED + Active Buzzer
 *
 * PCB: See wiring diagram. Star ground, 100nF decoupling per module.
 *      CT cable: twisted pair ≤15cm, shield grounded at PCB end only.
 * Telegram: set TELEGRAM_TOKEN + TELEGRAM_CHAT_ID, leave blank to disable.
 * Libraries: Adafruit PN532, SSD1306, GFX, ArduinoJson (others built-in).
 */

#include <Arduino.h>
#include <Wire.h>
#include <WiFi.h>
#include <WiFiClientSecure.h>
#include <WebServer.h>
#include <ArduinoJson.h>
#include <Preferences.h>
#include <Adafruit_PN532.h>
#include <Adafruit_SSD1306.h>
#include <Adafruit_GFX.h>
#include <math.h>
#include <time.h>

// ─── Wi-Fi ────────────────────────────────────────────────────
const char* WIFI_SSID     = "YOUR_WIFI_SSID";
const char* WIFI_PASSWORD = "YOUR_WIFI_PASSWORD";

// ─── Telegram ─────────────────────────────────────────────────
// Set to "" to disable. See setup guide in header above.
const char* TELEGRAM_TOKEN   = "";  // paste your bot token here, leave blank to disable
const char* TELEGRAM_CHAT_ID = "";  // paste your Telegram chat ID here
const char* TELEGRAM_HOST    = "api.telegram.org";

// ─── Pins ─────────────────────────────────────────────────────
const int ADC_PIN    = 34;
const int GREEN_LED  = 18;
const int RED_LED    = 19;
const int YELLOW_LED = 5;
const int BUZZER_PIN = 23;

// Sensor constants — CT ratio and burden determine the A/V conversion factor.
const float BURDEN_OHM  = 33.0f;
const float TURNS_RATIO = 2000.0f;

// Detection threshold in net amps (above ambient). Persisted in NVS, editable via Settings.
float gThreshold = 1.0f;

// gAmbientAmps: raw RMS baseline captured with machine off. Subtracted from every reading.
// gFilteredNet: EMA-smoothed net amps (after ambient subtraction). Used for all decisions.
// gMidpoint: ADC DC midpoint (~1834 at 3.3V/2). Drifts slowly with temperature.
float gAmbientAmps = 0.0f;
const float LP_ALPHA = 0.15f;
float gFilteredNet  = 0.0f;
float gMidpoint     = 1834.6f;

// ─── NVS ──────────────────────────────────────────────────────
Preferences prefs;

// ─── OLED ─────────────────────────────────────────────────────
#define SCREEN_WIDTH 128
#define SCREEN_HEIGHT 32
#define OLED_RESET   -1
#define OLED_ADDR    0x3C
Adafruit_SSD1306 display(SCREEN_WIDTH, SCREEN_HEIGHT, &Wire, OLED_RESET);

// ─── NFC ──────────────────────────────────────────────────────
Adafruit_PN532 nfc(21, 22);

// ─── Web server ───────────────────────────────────────────────
WebServer server(80);

// ─── Employees (NVS persisted) ────────────────────────────────
#define MAX_EMPLOYEES 20
struct Employee { char uid[20]; char name[64]; bool active; };
Employee employees[MAX_EMPLOYEES];
int      employeeCount = 0;

// Loads employees, ambient baseline, and threshold from NVS into RAM.
void nvsLoadEmployees() {
  prefs.begin("guardian", false);
  employeeCount = prefs.getInt("emp_count", 0);
  for (int i = 0; i < employeeCount && i < MAX_EMPLOYEES; i++) {
    char ku[16],kn[16],ka[16];
    snprintf(ku,16,"emp_uid_%d",i); snprintf(kn,16,"emp_name_%d",i); snprintf(ka,16,"emp_act_%d",i);
    prefs.getString(ku, employees[i].uid,  19);
    prefs.getString(kn, employees[i].name, 63);
    employees[i].active = prefs.getUChar(ka,1)!=0;
  }
  gAmbientAmps = prefs.getFloat("ambient",   0.0f);
  gThreshold   = prefs.getFloat("threshold", 1.0f);
  prefs.end();
  Serial.printf("[NVS] %d employees, ambient=%.3fA, threshold=%.2fA\n", employeeCount, gAmbientAmps, gThreshold);
}

// Writes all employee records to NVS. Called after every add/remove/toggle.
void nvsSaveEmployees() {
  prefs.begin("guardian", false);
  prefs.putInt("emp_count", employeeCount);
  for (int i = 0; i < employeeCount; i++) {
    char ku[16],kn[16],ka[16];
    snprintf(ku,16,"emp_uid_%d",i); snprintf(kn,16,"emp_name_%d",i); snprintf(ka,16,"emp_act_%d",i);
    prefs.putString(ku, employees[i].uid);
    prefs.putString(kn, employees[i].name);
    prefs.putUChar(ka,  employees[i].active?1:0);
  }
  prefs.end();
}

// Persists ambient baseline and threshold to NVS.
void nvsSaveCalibration() {
  prefs.begin("guardian",false);
  prefs.putFloat("ambient",   gAmbientAmps);
  prefs.putFloat("threshold", gThreshold);
  prefs.end();
}

bool isAuthorised(const String& uid, String& outName) {
  for (int i=0;i<employeeCount;i++) {
    if (employees[i].active && uid==String(employees[i].uid)) { outName=String(employees[i].name); return true; }
  }
  return false;
}

// ─── System state ─────────────────────────────────────────────
enum MachineState { STATE_IDLE, STATE_AUTHENTICATED, STATE_RUNNING, STATE_UNAUTHORIZED };
MachineState  currentState     = STATE_IDLE;
bool          machineOn        = false;
String        currentEmployee  = "";
String        currentUID       = "";
unsigned long authTime         = 0;
unsigned long machineStartTime = 0;
const unsigned long AUTH_TIMEOUT_MS = 30000;

// ─── Data storage ─────────────────────────────────────────────
#define MAX_SAMPLES 288
struct PowerSample  { unsigned long ts; float amps; float watts; };
struct RuntimeEntry {
  char date[11]; char employee[64]; unsigned long seconds;
  bool unauthorized;   // true = machine ran without auth
};
struct NotifEntry { unsigned long ts; char message[128]; char type[16]; };

PowerSample  powerLog[MAX_SAMPLES];
int          powerLogHead=0, powerLogCount=0;
RuntimeEntry runtimeLog[100];
int          runtimeLogCount=0;
NotifEntry   notifLog[50];
int          notifHead=0, notifCount=0;

unsigned long lastPowerSample=0;
const unsigned long POWER_SAMPLE_INTERVAL=5000;

// ─── Helpers ──────────────────────────────────────────────────

void addNotification(const char* msg, const char* type) {
  int idx=notifHead%50;
  notifLog[idx].ts=time(nullptr);
  strncpy(notifLog[idx].message,msg,127); notifLog[idx].message[127]='\0';
  strncpy(notifLog[idx].type,   type,15); notifLog[idx].type[15]='\0';
  notifHead++; if(notifCount<50)notifCount++;
  Serial.printf("[NOTIF][%s] %s\n",type,msg);
}

String uidToString(uint8_t* uid, uint8_t len) {
  if(!uid||len==0||len>7) return "";
  String s="";
  for(uint8_t i=0;i<len;i++){if(uid[i]<0x10)s+="0"; s+=String(uid[i],HEX);}
  s.toUpperCase(); return s;
}

String getDateString() {
  time_t now=time(nullptr); struct tm* t=localtime(&now);
  char buf[11]; snprintf(buf,11,"%04d-%02d-%02d",t->tm_year+1900,t->tm_mon+1,t->tm_mday);
  return String(buf);
}

// Records runtime — employee name is "UNAUTHORIZED" for unauth sessions
void recordRuntime(const String& emp, unsigned long sec, bool unauth=false) {
  String today=getDateString();
  for(int i=0;i<runtimeLogCount;i++) {
    if(String(runtimeLog[i].date)==today && String(runtimeLog[i].employee)==emp
       && runtimeLog[i].unauthorized==unauth)
      { runtimeLog[i].seconds+=sec; return; }
  }
  if(runtimeLogCount<100) {
    strncpy(runtimeLog[runtimeLogCount].date,    today.c_str(),10);
    strncpy(runtimeLog[runtimeLogCount].employee,emp.c_str(),  63);
    runtimeLog[runtimeLogCount].seconds=sec;
    runtimeLog[runtimeLogCount].unauthorized=unauth;
    runtimeLogCount++;
  }
}

// ─── Telegram ─────────────────────────────────────────────────
// Runs entirely on the ESP32 using WiFiClientSecure.
// HTTPS connection to api.telegram.org:443.
// certificate verification is skipped (setInsecure) — acceptable
// for this use case as the token itself provides authentication.

void sendTelegram(const char* text) {
  if(strlen(TELEGRAM_TOKEN)==0 || strlen(TELEGRAM_CHAT_ID)==0) return;
  if(WiFi.status()!=WL_CONNECTED) return;

  WiFiClientSecure client;
  client.setInsecure();  
  client.setTimeout(8000);

  if(!client.connect(TELEGRAM_HOST, 443)) {
    Serial.println("[TG] Connection failed");
    return;
  }

  
  String msg = String(text);
  msg.replace("\"","\\\"");

  String body = "{\"chat_id\":\"" + String(TELEGRAM_CHAT_ID) +
                "\",\"text\":\"" + msg +
                "\",\"parse_mode\":\"HTML\"}";

  String path = "/bot" + String(TELEGRAM_TOKEN) + "/sendMessage";

  client.println("POST " + path + " HTTP/1.1");
  client.println("Host: " + String(TELEGRAM_HOST));
  client.println("Content-Type: application/json");
  client.println("Content-Length: " + String(body.length()));
  client.println("Connection: close");
  client.println();
  client.print(body);

  
  unsigned long t=millis();
  while(client.connected() && millis()-t<5000) {
    if(client.available()) {
      String line=client.readStringUntil('\n');
      if(line.startsWith("HTTP/")) Serial.println("[TG] "+line);
      if(line=="\r") break;
    }
  }
  client.stop();
}

// ─── OLED ─────────────────────────────────────────────────────
void displayMessage(const char* l1, const char* l2="", const char* l3="") {
  display.clearDisplay(); display.setTextColor(SSD1306_WHITE); display.setTextSize(1);
  display.setCursor(0,0);  display.println(l1);
  if(l2[0]){display.setCursor(0,12);display.println(l2);}
  if(l3[0]){display.setCursor(0,24);display.println(l3);}
  display.display();
}

// ─── Buzzer ───────────────────────────────────────────────────
void beepShort(){digitalWrite(BUZZER_PIN,HIGH);delay(100);digitalWrite(BUZZER_PIN,LOW);}
void beepAlarm(){
  for(int i=0;i<6;i++){
    digitalWrite(RED_LED,HIGH);digitalWrite(BUZZER_PIN,HIGH);delay(150);
    digitalWrite(RED_LED,LOW); digitalWrite(BUZZER_PIN,LOW); delay(100);
  }
}

// ─── LEDs ─────────────────────────────────────────────────────
void setLEDs(bool r,bool y,bool g){
  digitalWrite(RED_LED,   r?HIGH:LOW);
  digitalWrite(YELLOW_LED,y?HIGH:LOW);
  digitalWrite(GREEN_LED, g?HIGH:LOW);
}

// ─── ADC measurement (I2C paused during sampling) ─────────────
float measureRawRMS() {
  Wire.end();  
  long sumSq=0,sumRaw=0;
  for(int i=0;i<2000;i++){
    int raw=analogRead(ADC_PIN);
    sumRaw+=raw;
    int off=raw-(int)gMidpoint;
    sumSq+=(long)off*off;
    delayMicroseconds(50);
  }
  Wire.begin(21,22);  
  float newMid=(float)sumRaw/2000.0f;
  gMidpoint=gMidpoint*0.97f+newMid*0.03f;
  float rmsADC=sqrtf((float)sumSq/2000.0f);
  float rmsV=rmsADC*(3.3f/4095.0f);
  return (rmsV/BURDEN_OHM)*TURNS_RATIO;
}

float measureNetAmps() {
  float raw=measureRawRMS();
  float net=raw-gAmbientAmps;
  if(net<0.0f) net=0.0f;
  if(net<0.3f) net=0.0f;
  gFilteredNet=LP_ALPHA*net+(1.0f-LP_ALPHA)*gFilteredNet;
  return gFilteredNet;
}

// Takes 30 raw RMS samples with machine off, averages them, adds 10% margin, saves to NVS.
float captureAmbient() {
  displayMessage("Measuring ambient","Machine must be OFF","Do not move clamp");
  float sum=0;
  for(int i=0;i<30;i++){sum+=measureRawRMS();delay(100);}
  float avg=sum/30.0f;
  gAmbientAmps=avg*1.1f;
  nvsSaveCalibration();
  gFilteredNet=0.0f;
  Serial.printf("[AMB] ambient=%.3fA\n",gAmbientAmps);
  return gAmbientAmps;
}

// ─── Unauthorized session tracking ────────────────────────────
bool          unauthRunning    = false;
unsigned long unauthStartTime  = 0;

void startUnauthSession() {
  unauthRunning   = true;
  unauthStartTime = millis();
}

void stopUnauthSession() {
  if(!unauthRunning) return;
  unsigned long sec=(millis()-unauthStartTime)/1000;
  if(sec>0) recordRuntime("UNAUTHORIZED",sec,true);
  unauthRunning=false;
}

// ─── State machine ────────────────────────────────────────────
void enterIdle() {
  currentState=STATE_IDLE; currentEmployee=""; currentUID="";
  setLEDs(true,false,false);
  displayMessage("Authentication","Required","Scan your card");
}

void enterAuthenticated(const String& emp) {
  currentState=STATE_AUTHENTICATED; currentEmployee=emp; authTime=millis();
  setLEDs(false,true,false);
  char l2[64]; snprintf(l2,64,"Welcome %s",emp.c_str());
  displayMessage("Machine Ready",l2,"Start the machine");
  beepShort();
  char notif[128]; snprintf(notif,128,"%s authenticated",emp.c_str());
  addNotification(notif,"info");
}

void enterRunning(float amps) {
  currentState=STATE_RUNNING; machineStartTime=millis();
  setLEDs(false,false,true);
  char l2[32]; snprintf(l2,32,"%.1fA / %.0fW",amps,amps*220.0f);
  displayMessage("Machine Running",l2,currentEmployee.c_str());
  char notif[128]; snprintf(notif,128,"Machine started by %s",currentEmployee.c_str());
  addNotification(notif,"info");
}

void enterUnauthorized() {
  currentState=STATE_UNAUTHORIZED;
  setLEDs(false,false,false);
  displayMessage("! UNAUTHORIZED !","Access denied","Contact supervisor");
  addNotification("Unauthorized machine start detected!","alarm");

  
  char tgMsg[200];
  snprintf(tgMsg,200,
    "<b>⚠ UNAUTHORIZED ACCESS</b>\n"
    "Machine: started without valid card\n"
    "Time: %s\n"
    "Location: Machine Guardian",
    getDateString().c_str());
  sendTelegram(tgMsg);

  beepAlarm();
  startUnauthSession();  
  enterIdle();
}

void handleMachineOff() {
  if(currentState==STATE_RUNNING) {
    unsigned long sec=(millis()-machineStartTime)/1000;
    recordRuntime(currentEmployee,sec,false);
    char notif[128]; snprintf(notif,128,"Machine stopped. %s ran for %lus",currentEmployee.c_str(),sec);
    addNotification(notif,"info");
  }
  stopUnauthSession();
  enterIdle();
}

// ─── NFC ──────────────────────────────────────────────────────
void checkNFC() {
  uint8_t uid[7]={0}; uint8_t uidLen=0;
  if(!nfc.readPassiveTargetID(PN532_MIFARE_ISO14443A,uid,&uidLen,100)) return;
  if(uidLen==0||uidLen>7) return;
  String uidStr=uidToString(uid,uidLen);
  if(!uidStr.length()) return;

  String emp="";
  bool auth=isAuthorised(uidStr,emp);
  Serial.printf("NFC: %s → %s\n",uidStr.c_str(),auth?emp.c_str():"UNKNOWN");

  if(!auth) {
    char notif[128]; snprintf(notif,128,"Unknown card: %s",uidStr.c_str());
    addNotification(notif,"warn");
    displayMessage("Unknown Card",uidStr.c_str(),"Not authorised");
    beepShort(); delay(100); beepShort(); delay(1500);
    if(currentState==STATE_IDLE) enterIdle();
    else if(currentState==STATE_RUNNING){
      char l2[32]; snprintf(l2,32,"%.1fA / %.0fW",gFilteredNet,gFilteredNet*220.0f);
      displayMessage("Machine Running",l2,currentEmployee.c_str());
    }
    return;
  }

  if(currentState==STATE_IDLE||currentState==STATE_AUTHENTICATED){
    currentUID=uidStr; enterAuthenticated(emp);
  } else if(currentState==STATE_RUNNING){
    if(currentUID==uidStr){addNotification((emp+" checked out").c_str(),"info");beepShort();}
    else{
      char notif[128]; snprintf(notif,128,"%s scanned while %s is running",emp.c_str(),currentEmployee.c_str());
      addNotification(notif,"warn");
    }
  }
}

// ─── Dashboard HTML ───────────────────────────────────────────
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
void loop() {
  server.handleClient();

  float amps=measureNetAmps();
  bool  on=(amps>=gThreshold);

  if(on&&!machineOn){
    machineOn=true;
    if     (currentState==STATE_AUTHENTICATED) { stopUnauthSession(); enterRunning(amps); }
    else if(currentState==STATE_IDLE)          { enterUnauthorized(); }
  } else if(!on&&machineOn){
    machineOn=false; handleMachineOff();
  }

  // Keep tracking unauthorized runtime while machine is on without auth
  if(machineOn && currentState==STATE_IDLE && unauthRunning) {
    
  }

  if(currentState==STATE_AUTHENTICATED&&millis()-authTime>AUTH_TIMEOUT_MS){
    addNotification("Auth timeout — machine not started","warn"); enterIdle();
  }

  if(currentState==STATE_RUNNING){
    static unsigned long lastDisp=0;
    if(millis()-lastDisp>2000){
      char l2[32]; snprintf(l2,32,"%.1fA / %.0fW",amps,amps*220.0f);
      displayMessage("Machine Running",l2,currentEmployee.c_str());
      lastDisp=millis();
    }
  }

  if(millis()-lastPowerSample>=POWER_SAMPLE_INTERVAL){
    lastPowerSample=millis();
    if(currentState==STATE_RUNNING&&amps>=gThreshold){
      int idx=powerLogHead%MAX_SAMPLES;
      powerLog[idx].ts=time(nullptr); powerLog[idx].amps=amps; powerLog[idx].watts=amps*220.0f;
      powerLogHead++; if(powerLogCount<MAX_SAMPLES)powerLogCount++;
    }
  }

  checkNFC();
  delay(50);
}
